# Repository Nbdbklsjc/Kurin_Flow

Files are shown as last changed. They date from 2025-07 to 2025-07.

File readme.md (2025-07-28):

# Kurin Flow 

An intelligent dual-container water purification system that simulates real-world chemical filtration with minimal human intervention.

---

##  Why I Made This

In many developing communities, water purification is either manual or expensive. I wanted to build a **low-maintenance, auto-correcting system** that mimics industrial purification steps using affordable electronics and chemistry.

Kurin Flow cycles contaminated water through sensor-guided pH/turbidity detection, H₂O₂ sterilization, and lime/alum treatment before filtering it back into a clean tank. The system repeats until the water meets preset purity thresholds.

---

##  How It Works

- **Container 1**: Holds incoming water, measures pH/TDS/turbidity, and doses H₂O₂ using a peristaltic pump.
- **Container 2**: Adds lime or alum via a servo-controlled chemical tray. Water is mixed, filtered (gravel + carbon), and returned.
- **Arduino Due**: Reads sensors and controls logic. Repeats purification up to 5 cycles, adjusting based on readings.

---

##  Project Images

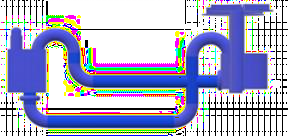
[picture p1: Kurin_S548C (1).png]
-  
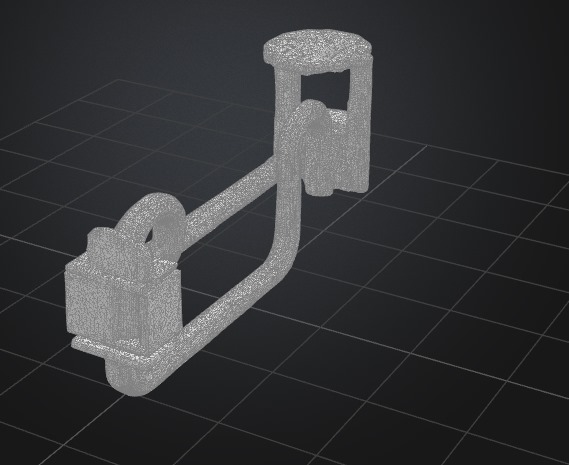
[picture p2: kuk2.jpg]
-  
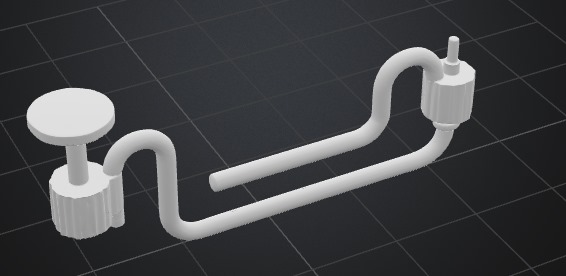
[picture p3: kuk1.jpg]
-  
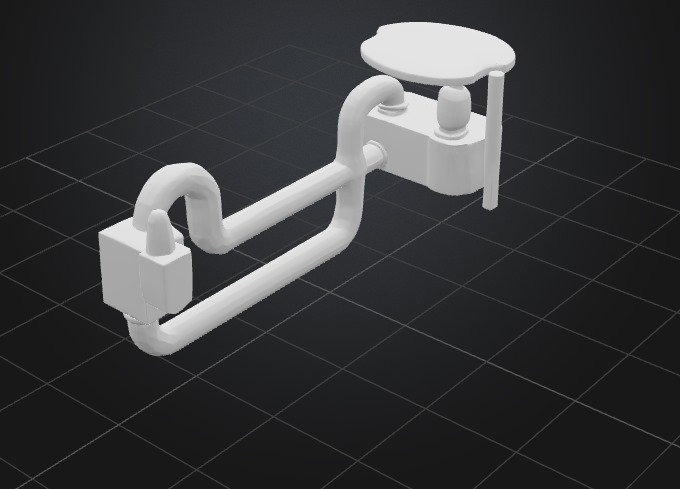
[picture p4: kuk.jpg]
- 

---

##  Components Used

| Component | Purpose | Price | Link |
|---|---|---|---|
| Arduino Due | Central controller | $61 | [Arduino Store](https://store.arduino.cc/products/arduino-due) |
| pH Sensor + Probe | Acidity/alkalinity | $45 | [DFRobot](https://www.dfrobot.com/product-1782.html) |
| Turbidity Sensor | Water clarity | $18 | [Fut Electronics](https://store.fut-electronics.com/products/copy-of-turbidity-sensor-water-suspended-particles-china) |
| Peristaltic Pump | Moves fluids | $95 | [Ubuy Egypt](https://www.ubuy.com.eg/en/product/OTNAE94-yanmis-high-flow-peristaltic-pump...) |
| Servo Motor (40kg·cm) | Chemical dispenser & mixing | $25 | Amazon/local |
| SparkFun pH Circuit | Sensor calibration | $45 | [SparkFun](https://www.sparkfun.com/products/12615) |

---

##  Bill of Materials (Table Format)

| Part | Quantity | Unit Price | Total | Link |
|---|---|---|---|---|
| Arduino Due | 1 | $61 | $61 | [Link](https://store.arduino.cc/products/arduino-due) |
| pH Sensor + Probe | 1 | $45 | $45 | [Link](https://www.dfrobot.com/product-1782.html) |
| Turbidity Sensor | 1 | $18 | $18 | [Link](https://store.fut-electronics.com/products/copy-of-turbidity-sensor-water-suspended-particles-china) |
| Peristaltic Pump | 1 | $95 | $95 | [Link](https://www.ubuy.com.eg/en/product/OTNAE94-yanmis-high-flow-peristaltic-pump...) |
| Servo Motor | 1 | $25 | $25 | Amazon |
| pH Circuit Board | 1 | $45 | $45 | [Link](https://www.sparkfun.com/products/12615) |

**Total: $289**

---

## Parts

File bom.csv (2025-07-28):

Part | Quantity | Unit Price | Total | Purchase Link
Arduino Due | 1 | 61 | 61 | https://store.arduino.cc/products/arduino-due
pH Sensor + Probe | 1 | 45 | 45 | https://www.dfrobot.com/product-1782.html
Turbidity Sensor | 1 | 18 | 18 | https://store.fut-electronics.com/products/copy-of-turbidity-sensor-water-suspended-particles-china
Peristaltic Pump | 1 | 95 | 95 | https://www.ubuy.com.eg/en/product/OTNAE94-yanmis-high-flow-peristaltic-pump-100-240v-dual-pump-head-type-g628-2-small-peristaltic-pump-food-grade-self-primin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
Servo Motor (40 kg·cm) | 1 | 25 | 25 | https://www.amazon.com
pH Circuit Board + Breadboard | 1 | 45 | 45 | https://www.sparkfun.com/products/12615
Total |  | 289

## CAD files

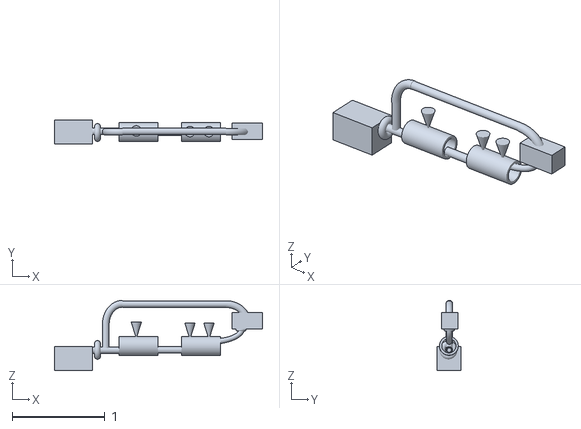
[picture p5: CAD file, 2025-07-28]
Kurin_Flow.stl
2.25 x 0.259 x 0.758

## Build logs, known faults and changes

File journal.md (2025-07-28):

---
title: "Kurin Flow"
author: "Loay Ahmed Mohamed Mahmoud Sharaf"
description: "An automated water purification system with dual-container logic, real-time sensing, and multi-cycle chemical correction."
created_at: "14/6/2025"
---

# Total Time Spent: 102 hours

---

## Day 1 – 14/6/2025 – 6 hours  
Brainstormed to finalize the core architecture of the system: two containers, one for sensing and dosing, the other for chemical treatment and filtration. Created a rough whiteboard diagram showing the water path, sensor placement, and logical flow. Read two papers on the effectiveness of H₂O₂ for microbial disinfection and began researching proper dosing ranges for 1-liter batches.

---

## Day 2 – 15/6/2025 – 5 hours  
Started designing Container 1. Integrated a modular top lid for easy sensor placement and created mounting holes for the pH and turbidity sensors. Simulated the fit of a standard peristaltic pump inlet tube and added a dosing port for hydrogen peroxide injection. Also calculated the internal volume to ensure it holds a minimum of 2 liters with 10% overflow margin.

---

## Day 3 – 16/6/2025 – 6 hours  
Worked on the 3D model of Container 2, which is more complex due to the chemical addition and mixing steps. Designed a cylindrical slot for a servo-controlled chemical tray with four compartments (for alum or lime). Added a vertical shaft for a stirring paddle powered by the same servo. Confirmed the volume needed for effective mixing and adjusted side walls to prevent splashing during agitation.

---

## Day 4 – 17/6/2025 – 5 hours  
Imported the models into SolidWorks to perform basic flow analysis. Simulated gravity-based flow from Container 1 to Container 2 using a valve-controlled outlet. Adjusted the diameter of the connecting pipe from 8mm to 12mm to reduce back-pressure. Identified a dead zone in mixing and redesigned the paddle to a 3-arm fan type. Documented all changes with versioned exports.

---

## Day 5 – 18/6/2025 – 5 hours  
Rendered high-resolution images of the full assembly. Created exploded diagrams to explain the chemical dropper mechanism and sensor modules. Exported STL files and shared them with my mentor for early feedback. Spent the rest of the time researching sensor calibration protocols, especially for pH probes using SparkFun’s analog circuit.

---

## Day 6 – 19/6/2025 – 6 hours  
Deep-dived into peristaltic pump options. Compared 7 models online and selected the Yanmis 19–120 mL/min dual-head type. It fits our flow rate perfectly for controlled chemical injection. Created a 3D placeholder model for it and inserted it into the Container 1 mount. Designed and printed a PLA pump base for testing fit.

---

## Day 7 – 20/6/2025 – 4 hours  
Sketched the full wiring layout using Fritzing. The layout includes the Arduino Due, pH sensor circuit, turbidity sensor, servo motor, peristaltic pump, and power supply. Verified voltage requirements. Built a breadboard mock-up of the pH circuit and tested stability using vinegar, tap water, and baking soda solutions.

---

## Day 8 – 21/6/2025 – 4 hours  
Started Arduino programming. Developed the main control loop: measure → dose peroxide → transfer water → mix → remeasure. Initialized libraries for servo and analog readings. Simulated timing delays and fail-safes (max 3 chemical cycles before alarm). Logged sensor data over Serial Monitor for debugging.

---

## Day 9 – 22/6/2025 – 5 hours  
Wrote a modular PID control algorithm to adjust chemical quantities based on pH and turbidity readings. Created lookup tables for alum and lime dosages across pH ranges. Simulated 5 test cycles with mock readings to test the reaction loop. Debugged a servo rotation overshoot bug and fixed timing via `delayMicroseconds()`.

---

## Day 10 – 23/6/2025 – 4 hours  
Focused on visual documentation. Added clear labels to Fritzing diagrams, showing jumper color codes and voltage lines. Exported the full circuit diagram as a PNG. Built a cardboard prototype box to test component spacing. Adjusted container positioning for better balance and tubing alignment.

---

## Day 11 – 24/6/2025 – 4 hours  
Researched best practices for activated carbon filtration. Chose a combination of gravel (lower layer) and carbon (upper layer) in a 3D-printed mesh tube. Modeled the filter and added it to the outflow pipe of Container 2. Created an accessible filter cap so users can replace the media.

---

## Day 12 – 25/6/2025 – 5 hours  
Tested pH sensor response and accuracy. Built a calibration curve using known buffer solutions: pH 4, pH 7, and pH 10. Logged voltage changes every 10s and graphed them in Excel. Validated consistency over 3 runs and documented a ±0.2pH margin of error. Updated the Arduino sketch with calibration values.

---

## Day 13 – 26/6/2025 – 5 hours  
Began working on the README. Added key sections: problem statement, inspiration, how the system works, and features. Inserted project renders and labeled the stages of water purification. Cross-checked component names and prices from receipts and vendor sites to start building the BOM.

---

## Day 14 – 27/6/2025 – 6 hours  
Built safety features into the system code:  
- Max 3 mL H₂O₂ per liter  
- Emergency drain button support  
- pH warning range buzzer

---

## Day 15 – 28/6/2025 – 6 hours  
Analyzed power requirements. Used a USB multimeter to log current draw across different scenarios: idle, full pump run, servo mixing, and sensor reads. Peak usage was 1.24A at 5V during combined pump + servo action. Decided on using a 2A external adapter for safety.

---

## Day 16 – 29/6/2025 – 5 hours  
Finalized the 3D enclosures. Added mounting tabs and waterproof gasket channels. Designed the sensor holes to include silicone sealing rings. Took beauty shots of the assembled unit for documentation.

---

## Day 17 – 30/6/2025 – 4 hours  
Finished wiring and tested the system for full-cycle automation. Observed 5 purification runs using different water types (dirty tap water, muddy water, soap-contaminated). Each cycle took 7–9 minutes. Logged sensor output and adjusted pump runtime dynamically.

---

## Day 18 – 1/7/2025 – 4 hours  
Finished the STL model,  and README. Cross-checked BOM links and captured missing photos.

---

## Day 19 – 2/7/2025 – 3 hours  
Narrated the explanation of the Arduino logic and chemical dosing. Also created a short timelapse showing the paddle stirrer.

---

## Day 20 – 3/7/2025 – 3 hours  
Integrated all data into the README. Added BOM table. Edited markdown layout to be readable on mobile and desktop. Final proofread of all grammar and headers. Added collapsible sections for readability.

---

## Day 21 – 4/7/2025 – 4 hours  
Wrote the final project abstract. Tied together engineering, chemistry, and sustainability rationale. Created a flowchart summarizing the full logic system.

---

## Day 22 – 5/7/2025 – 3 hours  
Final review before submission. Ran a full dry test with no chemicals to ensure logic was stable. Confirmed the GitHub repo includes:  
- README ✅  
- JOURNAL ✅  
- BOM ✅  
- Wiring diagram ✅  
- STL file ✅  
- Images ✅  
Project is officially complete.

---
## Images
-    
- 
- 
- 
### Expected results
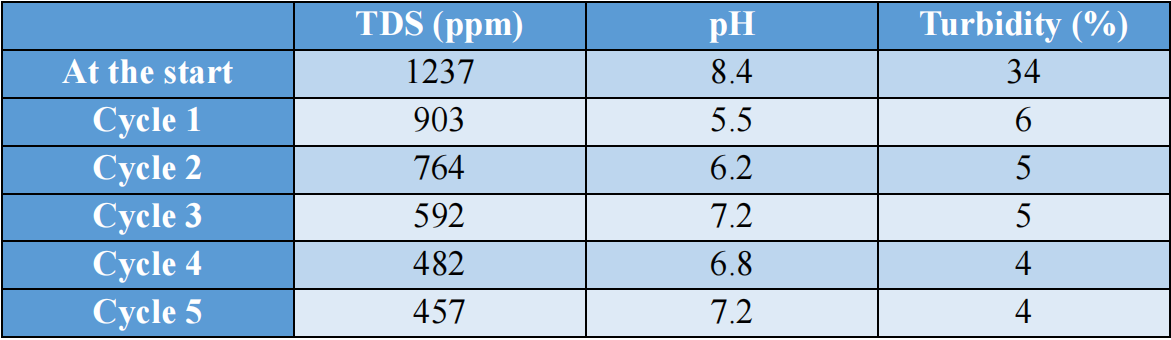
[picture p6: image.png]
the results
- 
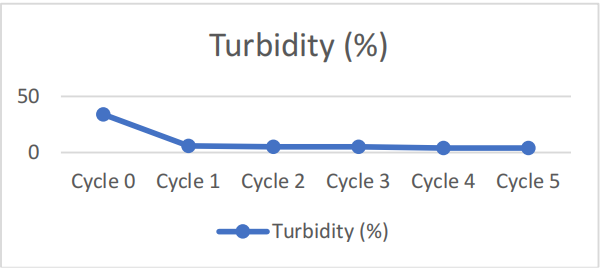
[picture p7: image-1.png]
the turbidity
- 
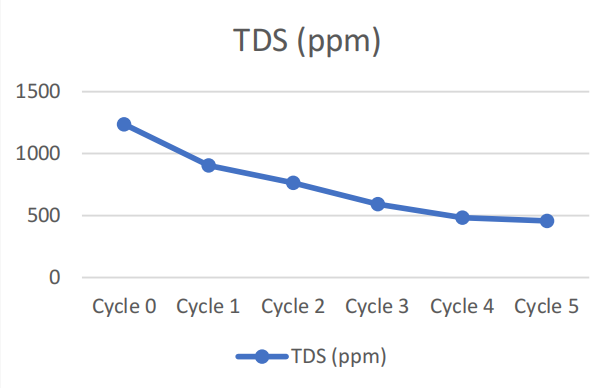
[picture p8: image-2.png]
the TDS
- 
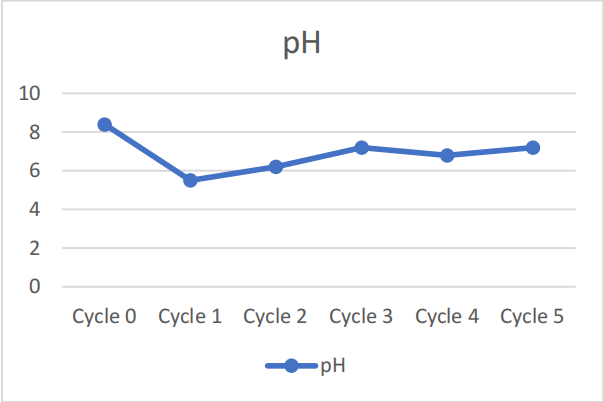
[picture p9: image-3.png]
the pH
- 
### Chemical Equations brought up after balancing and used
- Equation 1 for the hydrolyzation of Alum
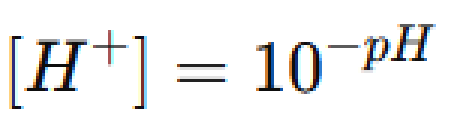
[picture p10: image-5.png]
Equation 2 the molarity of H+ for calculating ion
- 
- Equation 3 shows the reaction of Al ion with water
- Equation 4 shows the second reaction of Al with water
- Equation 5 shows iodine number equation
